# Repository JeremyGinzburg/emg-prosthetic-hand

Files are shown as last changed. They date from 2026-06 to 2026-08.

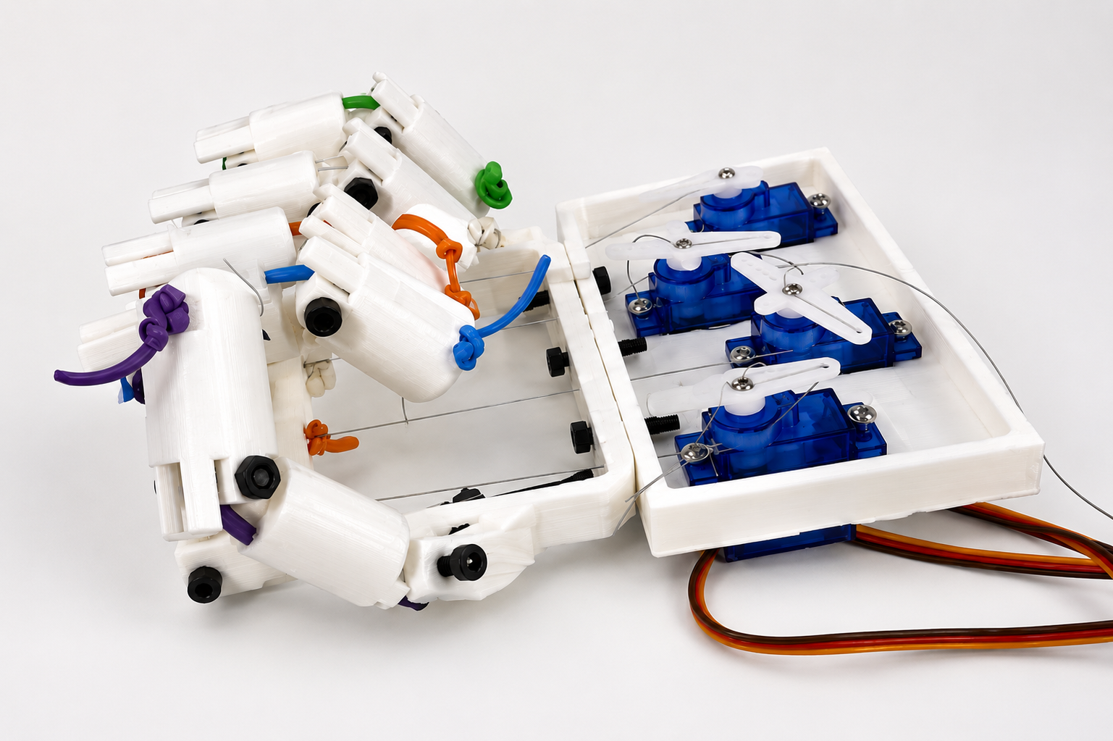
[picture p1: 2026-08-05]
docs/Hand Prototype.png

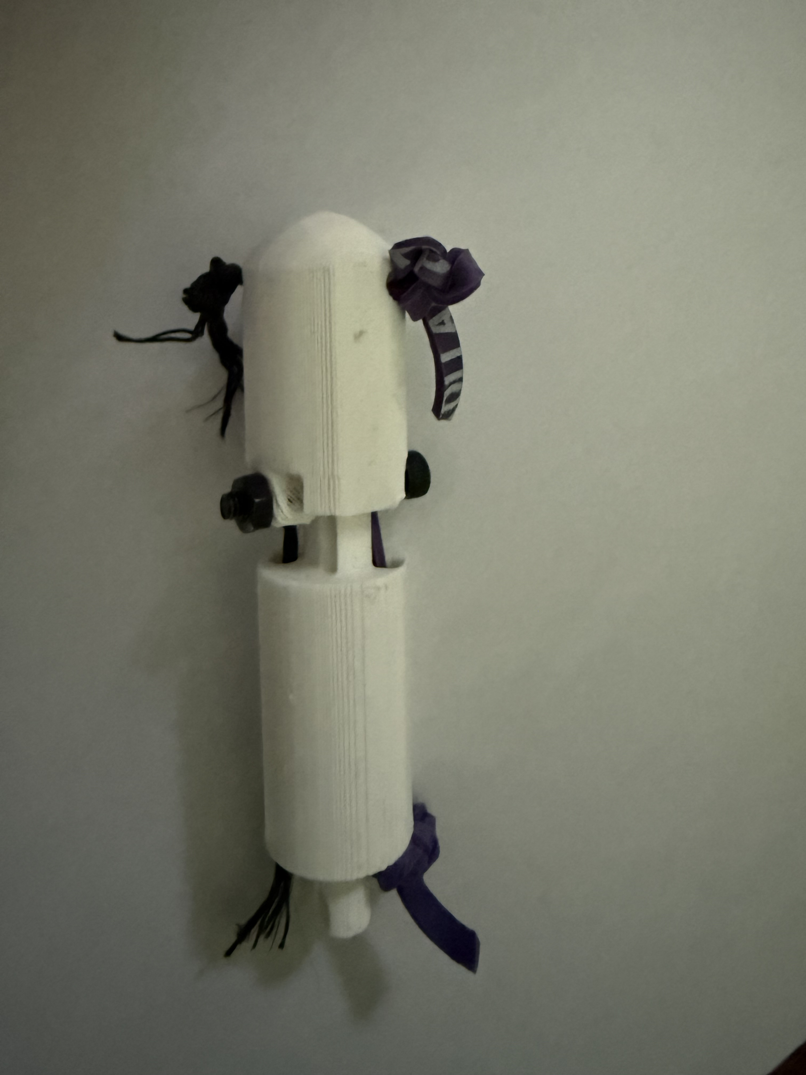
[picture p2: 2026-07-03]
docs/Tendon-Routed Finger.jpeg

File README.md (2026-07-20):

# EMG-Controlled 3D Printed Prosthetic Finger
3D-printed and EMG-controlled prosthetic hand with real-time signal processing and tendon-driven actuation. This project focuses on mechanical design, tendon routing, and iterative prototyping.

## Demo (Servo-Powered Finger Prototype)

https://github.com/user-attachments/assets/2a651c3f-5f36-4e6f-be27-cecad604387f

- Actuated motion is controlled by a servo pulling the fishing tackle, which bends the finger
- The rubber band snaps the fingers back into its neutral position when tension in the fishing tackle is released

## Overview
This project aims to develop a functional prosthetic finger that is controlled by a myoelectric (EMG) control system. The current stage focuses on prototyping a mechanically reliable, tendon-driven finger with multiple degrees of freedom and smooth actuation. 

The design uses a single tendon (rubber band) to drive flexion across two joints, modeling how biological fingers operate.

## How It Works
- A tendon (fishing tackle) runs through the finger segments and is anchored at the fingertip
- An SG90 servo pulls the tendon causes the finger to curl
- An elastic return mechanism will restore the finger to its original position

## Current Design
- 3D printed fingertip, middle segment, and temporary servo holder
- Two hinge joints held in place by M3 screws
- Internal tendon routing through hollow structures
- Tendon anchored at the fingertip
- SG90 servo powered by Arduino Uno
- Assembled and physically tested prototype

## Current Status
- CAD design implemented for 4-finger prototype
- Second prototype printed and assembled
- Joint motion validated
- Tendon integration and elastic return mechanism successfully implemented
- Wiring for SG90 servo and Arduino Uno completed

## Version History
- v1.0 - Initial Prototype
    - Desgined and printed finger components
    - Verified hinge joint motion
- v1.1 - Tendon Routing Improvements
    - Increased hole sizes for tendons
    - Adjusted hole placement to avoid interference with the hinge
- v1.2 - Functional Tendon-Driven Finger
    -  Implemented tendon (string) actuation
    -  Added elastic return mechanism
    -  Achieved full open-close motion across joints
    -  Demonstrates smooth flexion and passive extension
- v1.3 - Hardwired Servo-Powered Finger
    - Replaced string with fishing tackle for the tendon mechanism
    - Finger contracts by servo rotation instead of manual force
    - Observed consistent performance (50+ successful contractions with very few mechanical/electrical issues)
- v1.4 - Servo-Powered 4 Finger Prototype
    - Duplicated v1.3 to create 4 servo-powered fingers
    - Wired all SG90 servos to a breadboard and achieved GND/+5V using a 5V/3A wall wart
    - Hard-coded servo angles for open and close positions
  
## Design Decisions
- Tendon-Driven Actuation
    - Simple, lower weight, and similar to biological mechanisms
- Reduced Degrees of Freedom
    - Each joint has one hinge degree of freedom to ensure optimal control with a single tendon
- Internal Routing
    - Tendon is routed inside the hollow finger parts to protect it from wear and maintain consistent motion

## Challenges
- Finalize tendon routing within single finger and test full actuation
- Implement return mechanism using an elastic cord
- Redesign base and integrate into full finger
- Introduce servo control
- Transition into EMG-based signals

## Repository Structure
- /cad - Solidworks files and assemblies
- /docs - Images, videos, and selected references
- /logs - Engineering logs and iteration notes
- /firmware - (future) microcontroller and EMG code

## Acknowledgements
This project builds on tendon-driven prosthetics research as well as open-source mechanical designs, adapted and simplified for a first working prototype

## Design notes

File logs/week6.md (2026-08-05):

## July 27-29, 2026

### Goal
- 3D print a functional palm with a fully articulated thumb
- Program grasping motion using all 5 fingers

### What I Did
- Went through multiple iterations of 3D printing the newly designed palm
- Changed minor dimensions and spacing to improve overall finger control
- Reprinted fingers with 50% infill to improve structural durability
- Assembled 4 fingers and tested their functionality before adding the thumb

### Next Steps
- Implement thumb into the assembly

## July 31, 2026

### Goal
- Add the thumb and implement tendon routing

### What I Did
- Made a thumb finger using the same parts as the other 4 fingers, with the exception of the second finger joint
- Inserted the fishing tackle such that the thumb and index finger share one servo instead of implementing 5 servos
- Adjusted the thumb's fishing tackle to ensure that the fingers would not collide and that a complete grasping motion could be carried out. 

https://github.com/user-attachments/assets/f8d4579b-7863-490d-b478-92d41044ab2b

### Next Steps
- Improve aesthetics
- Implement Myoware EMG sensor and write filtering algorithms

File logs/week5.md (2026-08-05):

## July 19, 2026

### Goal
- Design an additional finger joint in Solidworks
- Rapidly prototype to ensure smooth finger flexion

### What I Did
- Create a new middle phalanx portion of the finger and added a second finger joint
- 3D printed multiple iterations and manually tested actuation

  

  

### Next Steps
- Print 4 updated fingers with the additional joint
- Get all of the fingers to bend through servo power

## July 20, 2026

### Goal
- Create a new 4 finger prototype with the additional joint in each finger
- Run Arduino code that has the fingers repeatedly extend and contract to determine any structural weaknesses

### What I Did
- Assembled the 4 finger prototype and recorded a video of repeated servo-powered actuation

https://github.com/user-attachments/assets/fcefc8ca-046b-4507-bcd2-b46573aede8d

### Next Steps
- Redesign the servo holder to mimic a palm structure
- Add a thumb finger to the side

## July 22, 2026

### Goal
- Duplicate servo holders to mimic a palm structure

### What I Did
- Designed a basic palm shape with 5 servo holders included to serve as a basic hand prototype

  

- Realized this design makes the palm too thick and doesn't accurately model a real hand

### Next Steps
- Think about a new design for the palm that doesn't involve stacking the servos inside the palm

## July 23-24, 2026

### Goal
- Redesign the palm so the SG90 servos are mounted in the forearm area

### What I Did
- Iterated through different designs in SolidWorks assemblies to create a palm structure and an external mounting piece for the servos
- Plan to attach the two pieces with M3 screws and increase the length of the fishing tackle

  Palm CAD


### Next Steps
- 3D print the updated palm assembly and test functionality

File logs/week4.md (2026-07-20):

## July 12, 2026

### Goal
- Design and print a temporary 4-servo holder that can attach four fingers
- Wire four SG90 servos to a breadboard and program them to rotate simultaneously

### What I Did
- Made a new part in Solidworks that duplicated the original single servo holder



- Powered and controlled four SG90 servos simultaneously using an external 5V/3A wall adapter
- Test code had all four servos rotate through a 40 degree range of motion without any Arduino resets
- Servos did not experience any jitters or delays

### Next Steps
- Finish printing the four-servo holder and attach fingers
- Line up tendons through all of the fingers and attach them to the SG90 servos
- Run test code to determine minimum and maximum angles for each individual servo

## July 14, 2026

### Goal
- Line up fishing tackle and elastic band for 4 finger mechanism
- Hardcode minimum and maximum angles in Arduino

### What I Did
- Assembled all 4 fingers with an identical structure to the first finger prototype
    - Made key adjustments to hole sizes (fishing tackle hole reduced to 1.35mm diameter; elastic band hole changed to an          elliptical shape)
- 3D printed newer prototypes to ensure smooth tendon routing in the future

### Next Steps
- Power all 4 fingers using a wall wart/breadboard circuit
- Write Arduino code to have the fingers open and close simultaneously

## July 15

### Goal
- Create a functional, servo-powered 4 finger prototype that can open and close repeatedly

### What I Did
- Wired the 4 servos to the breadboard and hardcoded the individual ranges for each finger
- Wrote a simple program that has the fingers open and close on repeat (code is under Four_Finger_Control in /firmware)

https://github.com/user-attachments/assets/708be8dc-0c76-421c-aebe-eec08a24979b

### Next Steps
- Add an additional joint on each finger to more accurately represent the human hand
- Design a more appropriate servo holder that mimics a palm structure

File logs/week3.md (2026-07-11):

## July 6, 2026

### Goal
- Replace string with fishing tackle
- Wire SG90 servo to the Arduino Uno

### What I Did
- Reprinted the fingertip and middle portion of the finger with smaller holes for the fishing tackle (see Fingertip (2) in /cad)
- Weaved the fishing tackle and reassembled the finger
- Wired the SG90 servo the Arduino Uno and wrote simple servo sweep code (see /firmware)

### Next Steps
- Tie the other end of the fishing tackle to the servo horn
- Upload the code and see if the servo can bend and unbend the finger

## July 7, 2026

### Goal
- Achieve servo-powered finger actuation

### What I Did
- Held the servo and finger in place while the servo rotated
- Observed successful finger actuation (see video in /docs)

### Next Steps
- Add a small mounting area to screw the SG90 servo in place

## July 8, 2026

### Goal
- Refine SG90 case and include a screw hole so it can be mounted

### What I Did
- Successfully redesigned the servo case to allow for the SG90 servo to be screwed in place
- Added a hole for the servo wires to go through
- Went through three iterations of Solidworks modeling and 3D printed iterations to ensure optimal placement



### Next Steps
- Practice coding in Arduino for controlling the extent that the finger is bent, rather then just having a servo sweep

## July 9, 2026

### Goal
- Write a program in Arduino that allows the user to input how much the finger should bend

### What I Did
- Used Arduino IDE to create a program allowing the user to input a number into the Serial Monitor that corresponds to the finger flexion (see Servo_Angle_Input in /firmware)
- Coded minimum and maximum values to ensure that there isn't slack or too much tension in the fishing tackle
- Wrote another program that has the finger continuously bend and unbend between the minimum and maximum values (see Continuous_Finger_Flexion in /docs)

### Next Steps
- Create a larger base in Solidworks to accomodate 3 additional fingers
- Map out circuit for a design with four fingers

## July 10, 2026

### Goal
- Design the circuit for the four finger mechanism in TinkerCad and roughly map out the wiring

### What I Did
- Created a circuit design and wrote code in TinkerCad to simulate running four servos simultaneously
    - NOTE: I decided to use the Arduino Uno's 5V pin in TinkerCad for voltage, but for the actual circuit I will be using a wall wart power supply with a barrel jack screw terminal adapter

https://github.com/user-attachments/assets/952dc470-4419-4437-9e56-5fa9d18c7a48

- Ordered necessary electrical parts to create this circuit (breadboard, wall wart, barrel jack screw terminal adapter)

### Next Steps
- Design a temporary base that can hold four SG90 servos and can attach the middle portion of the finger

## July 11, 2026

### Goal

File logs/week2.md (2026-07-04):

## June 28, 2026

### Goal
- Design channel for tendon that will allow for simple finger-bending motion

### What I Did
- Added holes in the fingertip and middle portion of the finger where an elastic band could be passed through
- Made sure the holes are lined up in assembly so the tendon doesn't have unnatural bending





### Next Steps
- Design base for the finger
- Research optimal methods for tendon wiring

## June 29, 2026

### Goal
- Model a simple base with screw holes to create a second degree of freedom
- 3D print all of the parts to observe joint functionality

### What I Did
- Designed a simple base that can be attached to the finger's middle portion at a joint
- 3D printed the base, middle portion, and the fingertip to see how they fit together
- Went through multiple sizing iterations to make sure that there was enough room for the joints to have a reasonable range of motion





### Next Steps
- Start adding screws and more permanent attachements for joint mechanism
- Begin attaching the tendon in the physical prototype
- Replicate the finger and attach it to a base

## July 1, 2026

### Goal
- Attach screws to 3D printed prototype to see if joint motion works
- Try weaving a string through the designated holes and see if pulling it will close the finger

### What I Did
- Tried adding screws to hold the joints in place, had to reprint with slightly larger screw holes (3mm --> 3.5mm)
- Began weaving the string through the hole and saw that the holes were too small
    - Started 3D printing with much larger holes (1.3mm --> 3mm)

### Next Steps
- Weave the rubber band into the screw holes and create a functional finger that bends when the string is pulled
- Start designing the back of the hand and replicating 3 more fingers (excluding thumb)

## July 3, 2026

### Goal
- Create a functional finger that opens when the string is pulled and closes using an elastic band

### What I Did
- Successfully weaved the string through the holes such that when the string is pulled, the finger closes
- Added a second pair of holes on the fingertip and middle pieces for the rubber band
- Attached the rubber band on the opposite side of the string and pulled the rubber band before attaching to increase tension
- Tested the finger's ability to manually open and automatically close

https://github.com/user-attachments/assets/4641aa62-4bc4-4c51-ac22-6a175d73874a

Tendon-Routed Finger

### Next Steps
- Replace manual hand pulling with a servo
- Replicate for more fingers

## July 4, 2026

### Goal
- Transition to controlling finger actuation by using a servo and Arduino

### What I Did
- Decided to use SG90 microservos and an Arduino (originally was going to use Arduino Nano, switching to Arduino Uno)
- Designed a temporary servo mount that attaches to the middle portion of the finger

### Next Steps
- Write and upload test code to the servo to ensure that it works and can be programmed properly
- Switch the string in the finger to fishing line so it can be weaved into the holes within the servo horn
- Test servo-controlled actuation

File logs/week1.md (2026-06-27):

## June 25, 2026

### Goal
Research existing prosthetic hand designs and identify realistic models for first prototype

### What I Did
- Reviewed wrist mechanism that uses 3 servos, bevel gears, timing belts, and a parallel manipulator for rotation (Source: https://pmc.ncbi.nlm.nih.gov/articles/PMC6140102/#sec5)
- Analyzed 20+ degrees of freedom in human hands (how fingers and wrist bend) (Source: https://www.researchgate.net/figure/Full-degrees-of-freedom-of-a-hand-It-involves-the-use-of-26-DOFs-being-3-for-the_fig3_2579054)

### Relevance to Project
- Decided on using coupled finger joints to reduce the number of motors/servos required
- Will explore the idea of using timing belts in the wrist mechanism (not final)

### Next Steps
- Research prosthetic models in public repositories
- Begin initial CAD designs for fingers in Solidworks

## June 26, 2026

### Goal
Begin designing fingertip with joint attachement in Solidworks

### What I Did
- Modeled a simple hollow fingertip using the Revolve and Shell tools
- Added two tabs with M3 screw holes for a joint mechanism

  

### Next Steps
- Design middle portion of finger that fits into the fingertip
- Experiment with Solidworks Assembly

## June 27, 2026

### Goal
Design middle portion of finger and try attaching it to fingertip in Assembly

### What I Did
- Modeled a simple middle portion of the finger with an M3 screw hole for joint movement
- Attached the two pieces together in Assembly

  
  

- Joint mechanism looks feasible in Assembly
- Realized that the tabs with screw holes on the fingertip are too far apart, so the two parts would slide horizontally against each other

### Next Steps
- Modify the fingertip and middle portion of the finger so the joint has only one degree of freedom
- 3D print both pieces and try attaching them together

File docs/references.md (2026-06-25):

## References
1. Mechanical Design and Assessment of a Low-Cost 7-DOF Prosthetic Arm for Shoulder Disarticulation - https://pmc.ncbi.nlm.nih.gov/articles/PMC6140102/#sec5
    Note: Wrist mechanism using timing belts and bevel gears
2. 3D Hand Tracker for Visual Sign Recognition - https://www.researchgate.net/figure/Full-degrees-of-freedom-of-a-hand-It-involves-the-use-of-26-DOFs-being-3-for-the_fig3_2579054
    Note: Human hand contains 20+ degrees of freedom - my design will use coupled finger movement and a single actuator

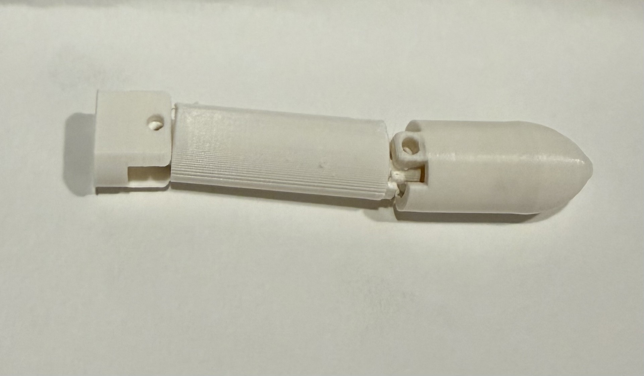
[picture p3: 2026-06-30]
docs/Finger v1.jpg

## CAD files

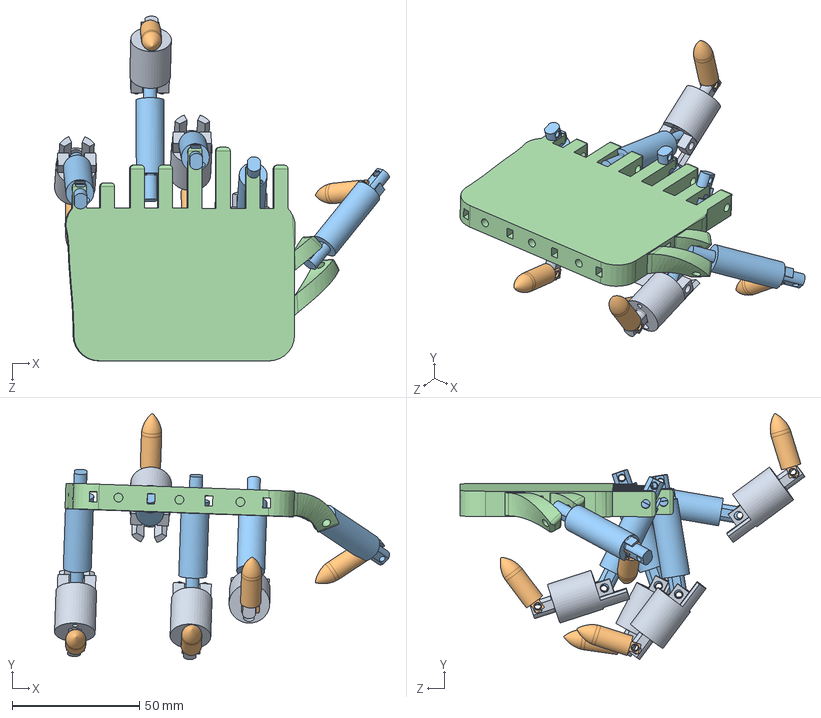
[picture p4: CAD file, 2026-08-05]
cad/Fingers + Palm_2 Assembly.SLDASM
131.7 x 96.8 x 135.6 mm
Palm_2
Finger_Middle x 5
Fingertip x 5
Finger_Bottom x 4

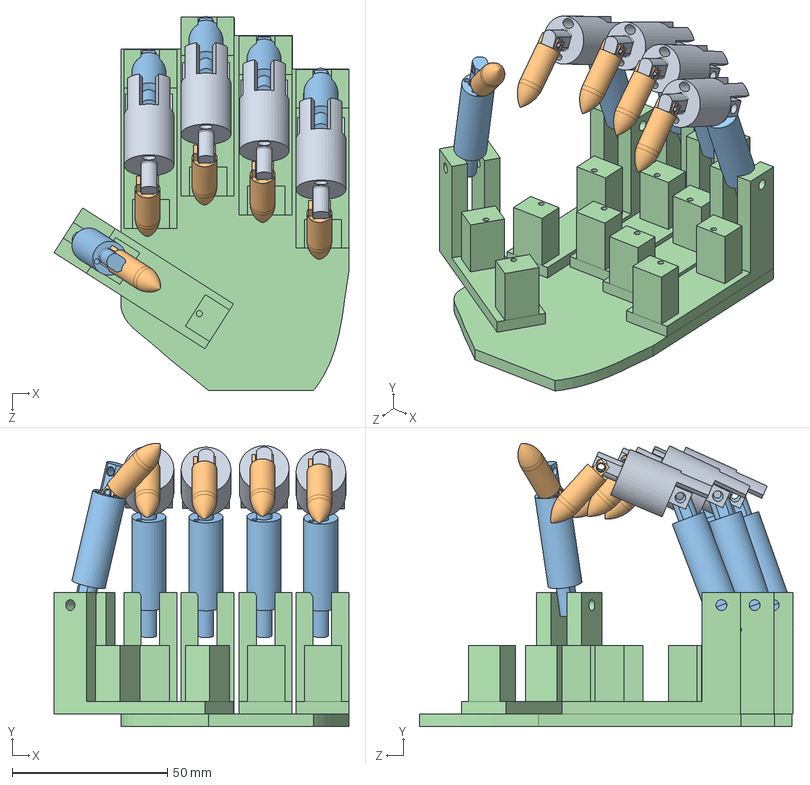
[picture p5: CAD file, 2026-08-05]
cad/Fingers + Palm Assembly.SLDASM
94.8 x 91.1 x 120.3 mm
Palm_1
Finger_Middle x 5
Fingertip x 5
Finger_Bottom x 4

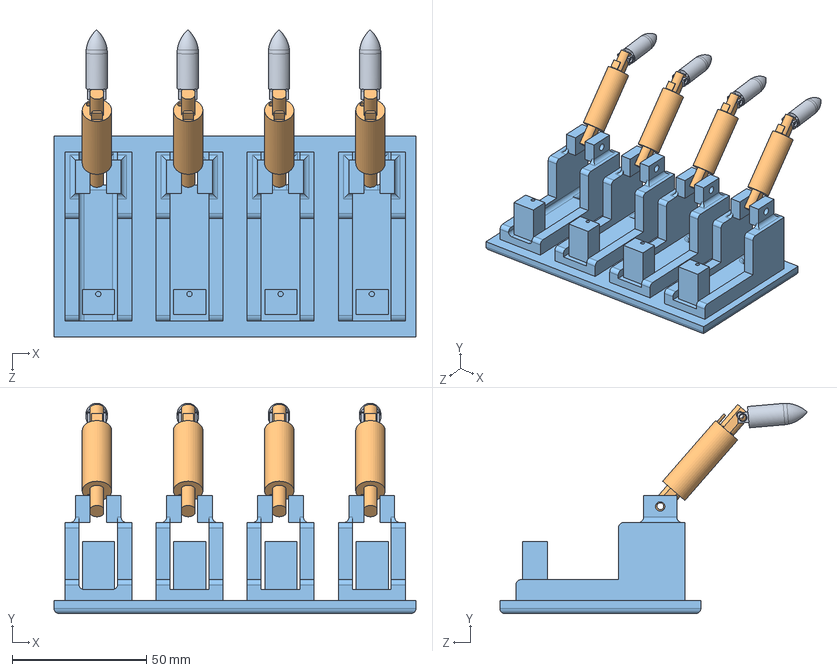
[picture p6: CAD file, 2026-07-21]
cad/Four Finger Assembly.SLDASM
135.0 x 78.5 x 114.7 mm
Four Finger Base
Finger_Middle x 4
Fingertip x 4

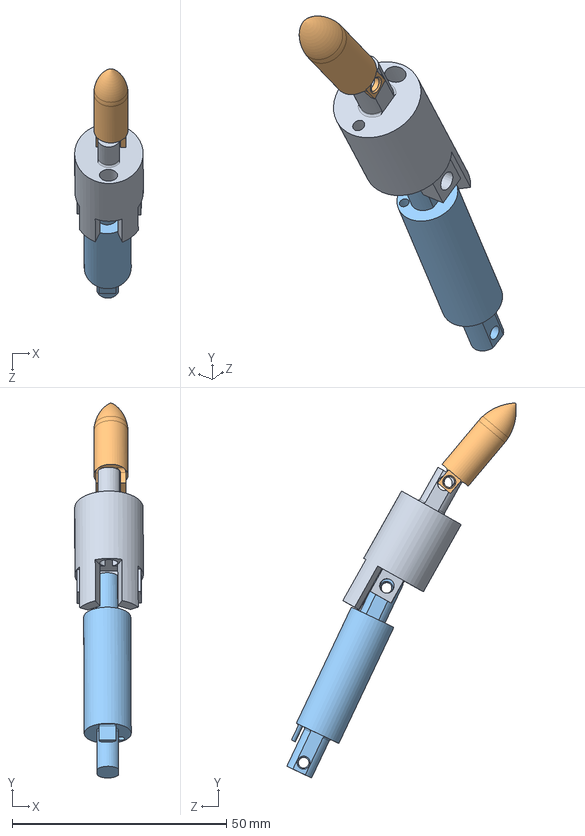
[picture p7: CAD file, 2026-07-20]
cad/Finger Assembly.SLDASM
16.1 x 87.5 x 53.5 mm
Finger_Middle
Fingertip
Finger_Bottom

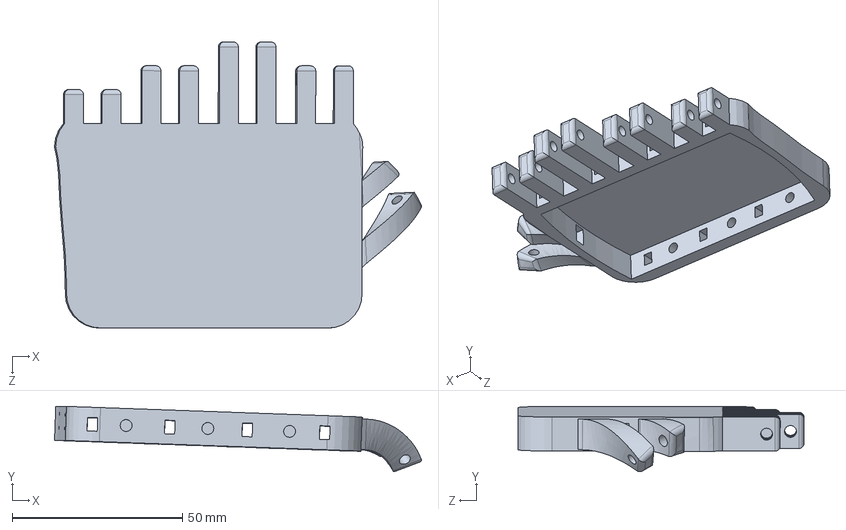
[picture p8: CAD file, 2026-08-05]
cad/Palm_2.SLDPRT
107.7 x 19.2 x 84.0 mm

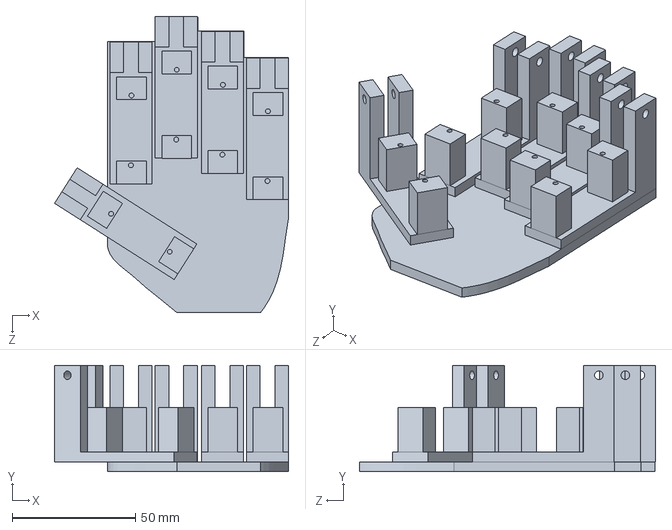
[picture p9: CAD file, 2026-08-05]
cad/Palm_1.SLDPRT
94.8 x 43.1 x 120.1 mm

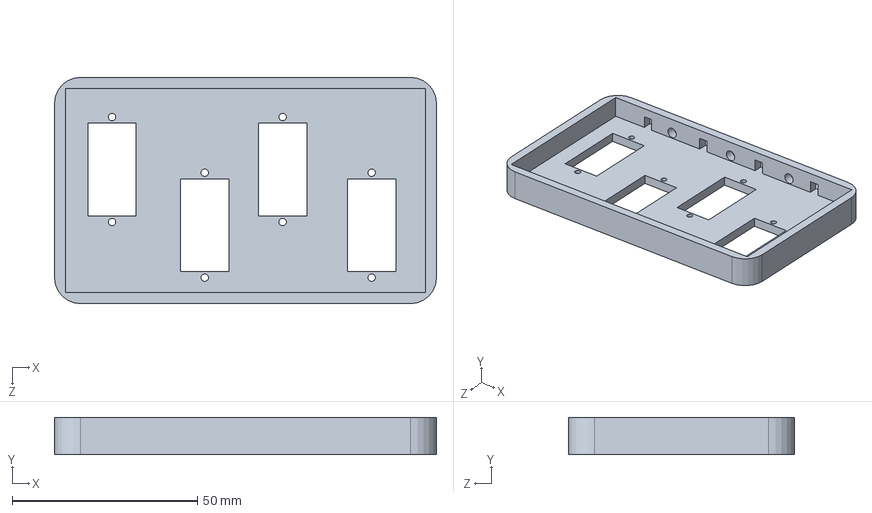
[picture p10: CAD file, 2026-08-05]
cad/Servo_Holder.SLDPRT
103.0 x 10.0 x 61.0 mm

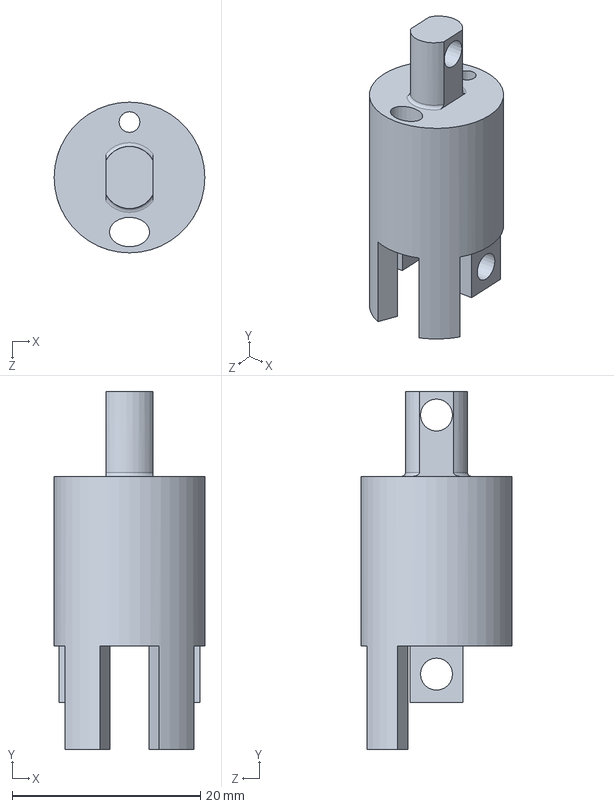
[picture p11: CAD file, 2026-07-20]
cad/Finger_Bottom.SLDPRT
16.0 x 38.0 x 16.0 mm

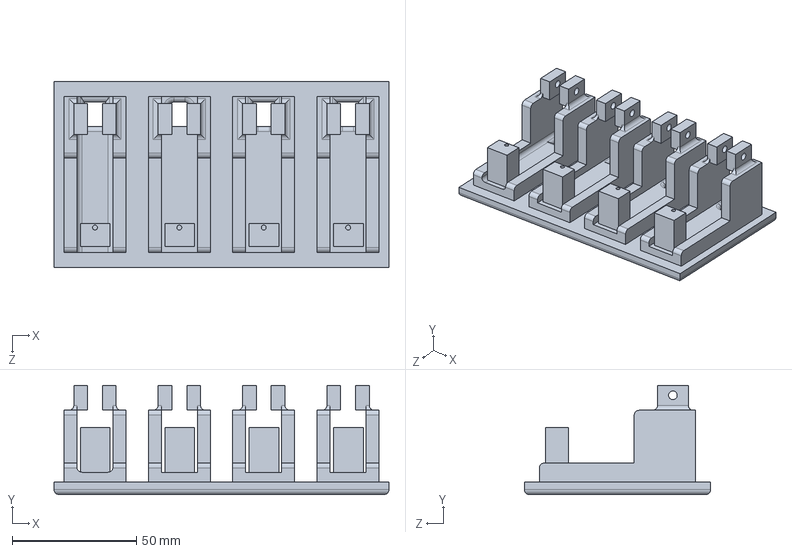
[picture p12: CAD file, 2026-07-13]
cad/Four Finger Base.SLDPRT
135.0 x 44.0 x 75.0 mm

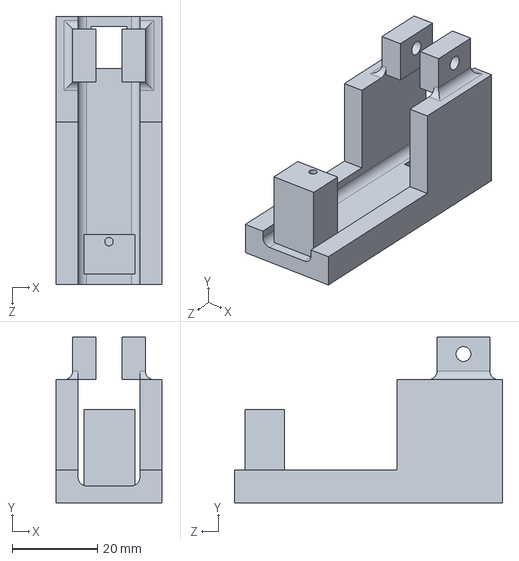
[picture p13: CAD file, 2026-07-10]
cad/SG90 Servo Mount.SLDPRT
25.0 x 39.0 x 63.0 mm

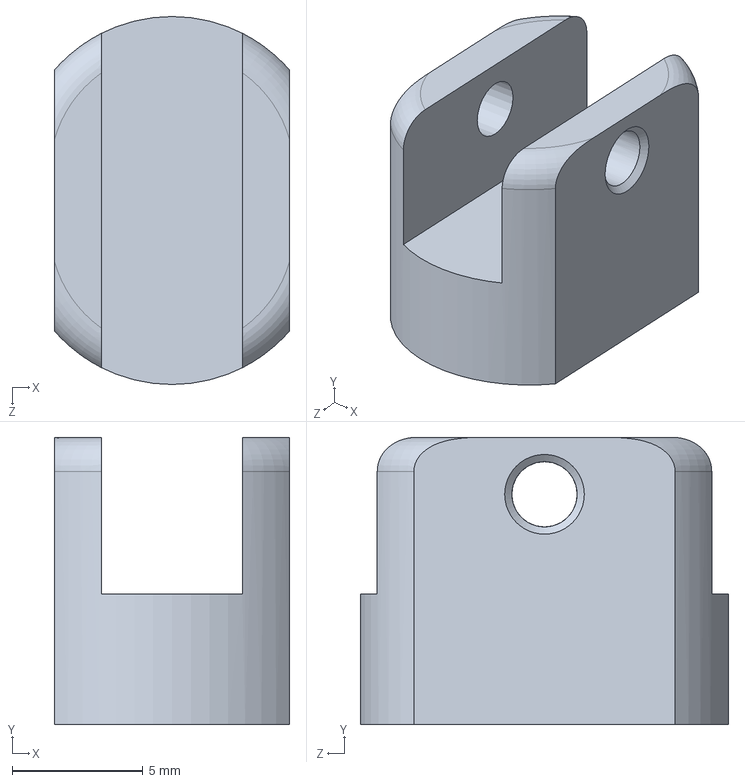
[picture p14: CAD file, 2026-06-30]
cad/Finger_Base.SLDPRT
9.00 x 11.0 x 14.1 mm

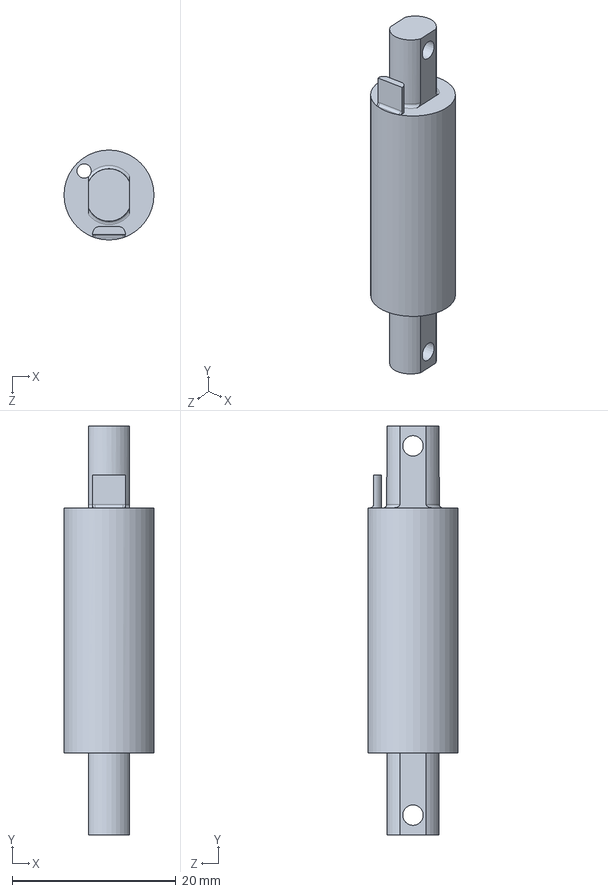
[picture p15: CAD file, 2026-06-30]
cad/Finger_Middle.SLDPRT
11.0 x 50.0 x 11.0 mm

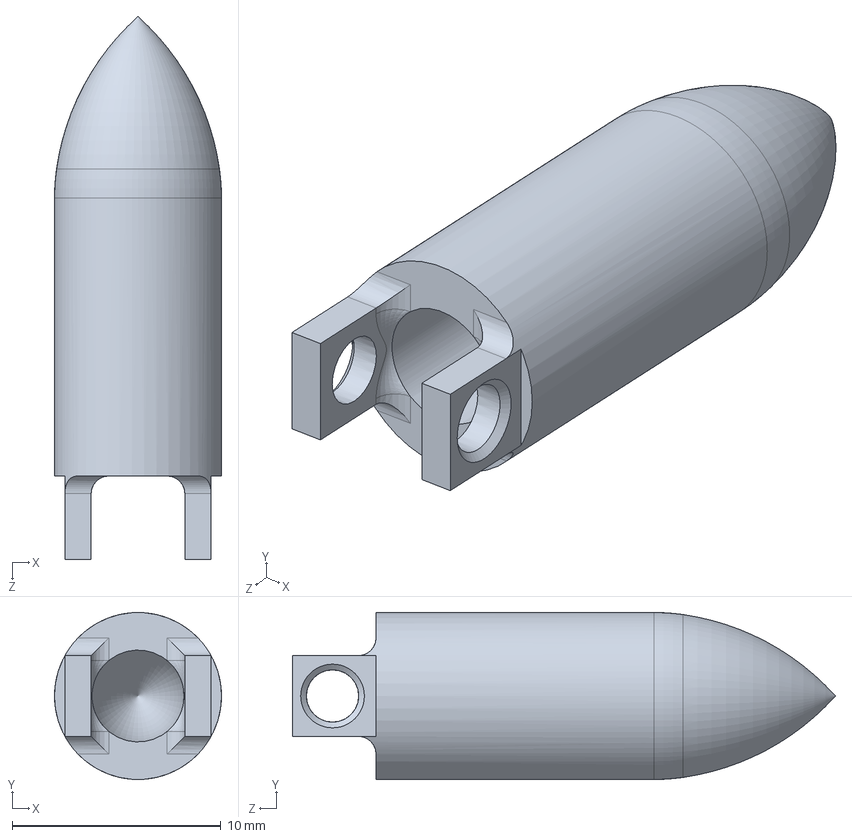
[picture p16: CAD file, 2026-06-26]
cad/Fingertip.SLDPRT
8.00 x 8.00 x 26.0 mm

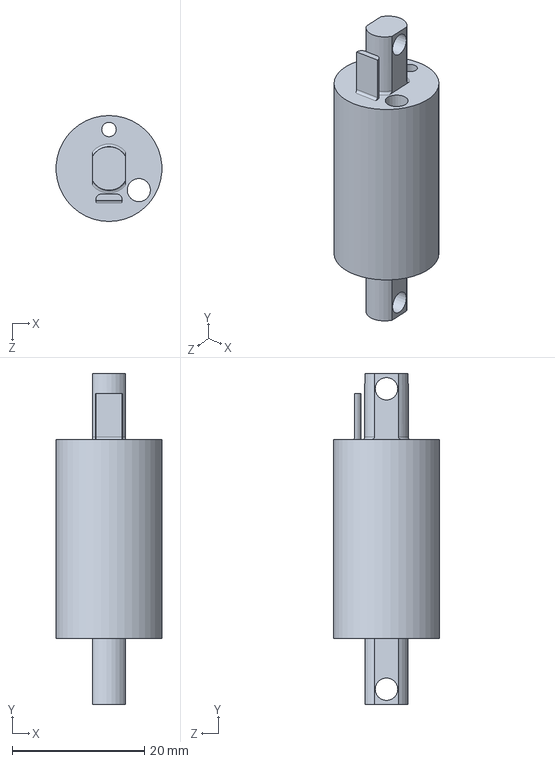
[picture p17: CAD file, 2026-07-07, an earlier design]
cad/Finger_Middle (2).SLDPRT
16.0 x 50.0 x 16.0 mm

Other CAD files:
cad/Servo Motor + Mount Assembly.SLDASM
cad/Fingertip (2).SLDPRT

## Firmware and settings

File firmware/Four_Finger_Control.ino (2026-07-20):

#include <Servo.h>

Servo servo1;
Servo servo2;
Servo servo3;
Servo servo4;

void setup() {
  // put your setup code here, to run once:
  servo1.attach(11);
  servo2.attach(9);
  servo3.attach(7);
  servo4.attach(5);
  Serial.begin(9600);

}

void loop() {
  // put your main code here, to run repeatedly:
  open();
  delay(1500);
  close();
  delay(1500);

}

void open() {
  servo1.write(180);
  servo2.write(75);
  servo3.write(80);
  servo4.write(100);
}

void close() {
  servo1.write(70);
  servo2.write(130);
  servo3.write(130);
  servo4.write(160);
}

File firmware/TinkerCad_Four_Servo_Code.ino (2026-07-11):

#include <Servo.h>

Servo servo1;
Servo servo2;
Servo servo3;
Servo servo4;

int minAngle = 75;
int maxAngle = 130;

int pos = minAngle;

void setup() {
  // put your setup code here, to run once:
  servo1.attach(9);
  servo2.attach(7);
  servo3.attach(3);
  servo4.attach(2);
  Serial.begin(9600);

}

void loop() {
  // put your main code here, to run repeatedly:
  for (int i = minAngle; i <= maxAngle; i++) {
    servo1.write(i);
    servo2.write(i);
    servo3.write(i);
    servo4.write(i);
    delay(15);
  }
  for (int j = maxAngle; j >= minAngle; j--) {
    servo1.write(j);
    servo2.write(j);
    servo3.write(j);
    servo4.write(j);
    delay(15);
  }

}

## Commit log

2026-06-26 Create Fingertip1
2026-07-02 Rename Finger (1).jpg to Finger v1.jpg
2026-07-07 Create Servo Sweep Test
